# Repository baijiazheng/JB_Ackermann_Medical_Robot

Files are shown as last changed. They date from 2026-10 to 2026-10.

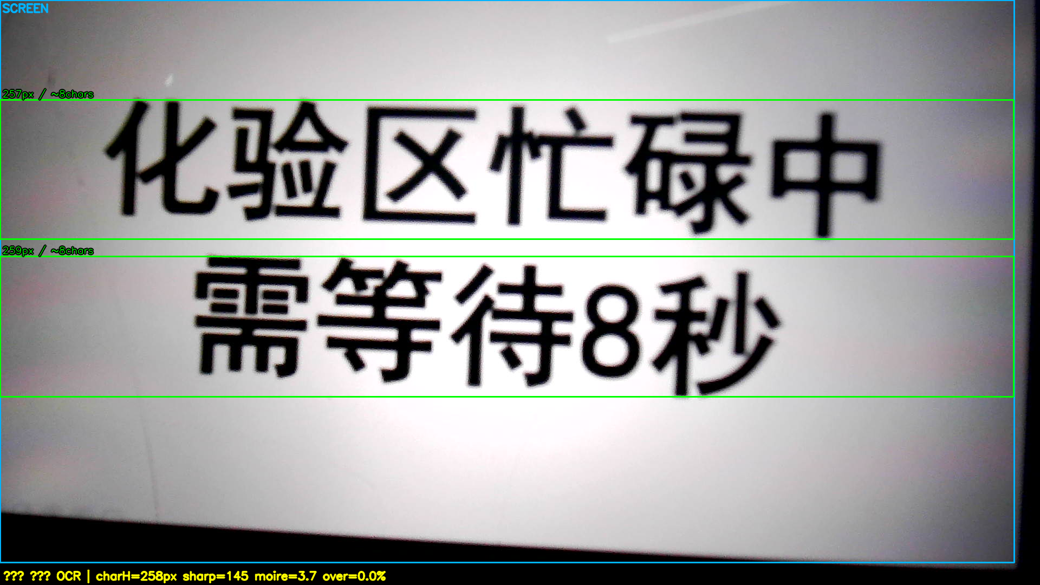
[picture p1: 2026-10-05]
experiments/01-拍屏OCR可行性/shots/annotated/shot_20261005_204455_01.png

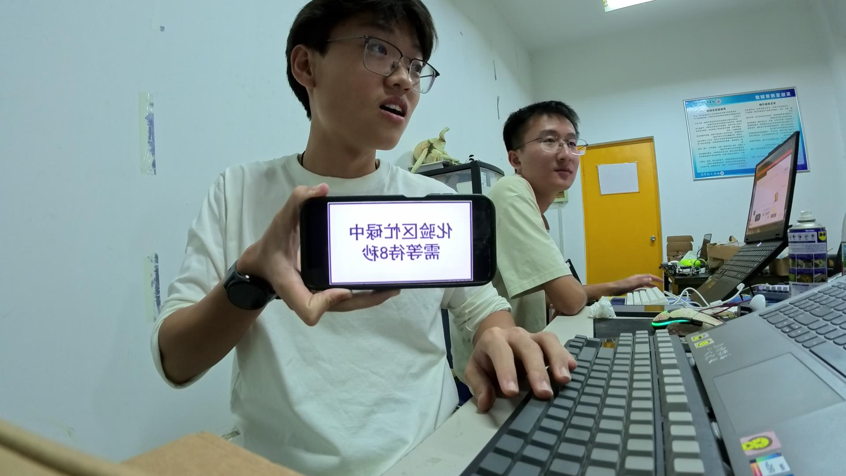
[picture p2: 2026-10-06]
experiments/01-拍屏OCR可行性/shots/shot_20261005_210529_01.png

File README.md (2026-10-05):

# JB_Ackermann_Medical_Robot

> **华北五省（市、自治区）大学生机器人大赛 · 智慧医疗服务机器人（专项赛道）**
> 一台**可无限复用的阿克曼底盘**，本轮承载「智慧医疗服务机器人」任务。

---

## 这是什么

一台能**看懂信息 → 说出来 → 自己开进框**的阿克曼底盘小车。

```
摄像头看到二维码/标签
      ↓
上位机（RDK X3 + ROS2）识别语义，判断"指向哪个体检窗口、什么样本"
      ↓
下发目标转角 δ + 目标速度 v
      ↓
下位机（Mega2560 背板）执行：舵机转向 + I²C 电机 + 语音播报
      ↓
AS5600 实测转角 + 编码器里程 + MPU6050 姿态 + 磁定位 → 闭环
      ↓
精准开进框
```

## 核心设计取向

| 取向 | 说明 |
|---|---|
| **阿克曼转向** | 比赛规则硬性要求（`底盘结构：阿克曼结构`）|
| **底盘永久复用** | 机械 + 背板 + 线束一次做对；以后换主控/换任务只动局部 |
| **三层分离** | 上位机（感知/决策）· 下位机（执行）· 外设接口板（背板，不变）|
| **全程端子** | 不用杜邦线 |
| **算法在上位机** | 下位机只做「指令 → 执行」，不写 PID |

## 目录

```
├── docs/                     方案与决策
│   ├── 01-比赛任务与规则.md
│   ├── 02-系统架构.md
│   ├── 03-阿克曼底盘参数.md     ★ 整车几何基准（唯一有效参数源）
│   └── 04-软件架构.md
├── hardware/
│   ├── mechanical/           机械件
│   │   ├── STL/              导出模型（转向节 / 底板 / 前桥 / 装配）
│   │   └── 图纸/             实测与定位尺寸图
│   └── electronics/          电控（BOM / 接线）
├── firmware/                 下位机（Arduino / 未来 STM32）
│   └── include/HW_CONFIG.h
└── ros2_ws/                  上位机（ROS2）
```

## 关联仓库

| 仓库 | 内容 |
|---|---|
| **[JB_Board](https://github.com/baijiazheng/JB_Board)** | 控制板家族 —— 本车用 **V1.2 阿克曼底盘背板** |
| [JB_AprilTag_Tracker](https://github.com/baijiazheng/JB_AprilTag_Tracker) | 视觉追踪（前代项目，代码可复用）|

## 进度

| 模块 | 状态 |
|---|---|
| 转向节（羊角）| ✅ 建模完成 |
| 前桥横梁 / 底板 | ✅ 建模完成 |
| 车架 | 🚧 待画 |
| 控制板 V1.2 | 🚧 设计输入完成，待画板 |
| 上位机软件 | ⏳ 等硬件 |
| 下位机固件 | ⏳ 等硬件 |

## 关键时间点

- 校赛答辩：**2026-09-23** ✅ 已通过
- 采购下单 T-22：**2026-10-12**

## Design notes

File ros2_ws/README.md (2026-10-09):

# ros2_ws · JB 阿克曼底盘上位机工作区

> **在本机写代码 → 验证语法 → `scp` 到 RDK X3 编译运行**
> （X3 上直接用 SSH 编辑不方便，所以本地开发 + 远程部署）

## 环境

| 项 | 值 |
|---|---|
| **目标板** | RDK X3（`ssh rdk`，IP `192.168.172.236`）|
| **系统** | Ubuntu 22.04.5 LTS / 内核 4.14.87 aarch64 |
| **ROS** | Humble（`/opt/ros/humble` + `/opt/tros/humble` TogetheROS）|
| **工作区** | X3 上 `~/ros2_ws`（本机这个目录是源码镜像）|

## 部署流程

```bash
# ① 本机写代码
cd ~/JB_Ackermann_Medical_Robot/ros2_ws/src/<包名>

# ② 本机语法检查（不需要 ROS 环境）
python3 -c "import ast;ast.parse(open('xxx.py',encoding='utf-8').read())"

# ③ 传到 X3
scp -r <包名> rdk:~/ros2_ws/src/

# ④ X3 上编译运行
ssh rdk
source ~/ros2_ws/setup_env.sh
cd ~/ros2_ws && colcon build --packages-select <包名>
ros2 run <包名> <可执行名>
```

## 已有的包

### `jb_camera_test` —— 摄像头测试

| 可执行 | 作用 |
|---|---|
| `camera_test` | 打开 USB 摄像头，发 `/camera/image_raw`，打印实测分辨率/帧率 |
| `camera_sub` | 订阅图像，统计帧率 + **端到端延迟**，可按需存图 |

**跑法：**
```bash
ros2 launch jb_camera_test camera_test.launch.py
# 或单独跑
ros2 run jb_camera_test camera_test --ros-args -p device:=/dev/video8
ros2 run jb_camera_test camera_sub  --ros-args -p save_every_n:=30
```

**实测结果（2026-10-09）：**
```
摄像头 /dev/video8  →  1280x720 @ 30fps  MJPG
发布/订阅帧率: 20.1 fps（USB 2.0 带宽上限）
★ 端到端延迟: 平均 19ms，最大 55ms   → 1m/s 下车只走 1.9cm，完全够用
```

## ⚠️ 踩过的坑

| # | 坑 | 修法 |
|---|---|---|
| **1** | **`ros2 run` 报 `No executable found`，但 colcon 编译"成功"** | **ament_python 包必须有 `setup.cfg`**（指定 `script_dir=$base/lib/<包名>`）否则脚本装不到 `ros2 run` 能找到的地方 |
| **2** | 摄像头只有 640x480，达不到 720p | **必须显式设置 MJPG**：`cap.set(cv2.CAP_PROP_FOURCC, fourcc('MJPG'))`。USB 2.0 带宽不够跑 YUYV 720p |
| **3** | 请求 1920x1080 却拿到别的分辨率 | 摄像头不一定给要的值 → **必须读回实际值**（`cap.get(CAP_PROP_FRAME_WIDTH)`）|

## 硬件设备

| 设备 | 节点 | 说明 |
|---|---|---|
| **摄像头** | `/dev/video8` | USB 2.0 Camera (Microdia)，video0~7 是地平线 ISP 虚拟节点 |
| **雷达** | `/dev/ttyUSB0` | CP2102 USB-UART 桥（待接）|

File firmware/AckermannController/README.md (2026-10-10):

# AckermannController · 阿克曼底盘下位机固件

> **目标板**：RobotDyn Mega 2560 PRO MINI
> **基于**：`JB_AprilTag_Tracker/firmware/Mega2560` 改造（复用 `MotorDriverI2C` + `UartProtocol`）

## 整体架构

```
RDK X3（上位机）                   Mega2560（下位机）
┌──────────────┐   Serial1    ┌──────────────────────┐
│ 视觉 / 雷达   │ ──────────→  │ UartProtocol 解析指令 │
│ 决策         │  v, ω        │        ↓             │
└──────────────┘              │ AckermannDrive       │
                              │   ├→ ServoSteering → 舵机 D5
                              │   └→ MotorDriverI2C → 电机模块 I²C 0x34
                              └──────────────────────┘
```

## 文件

| 文件 | 作用 |
|---|---|
| `include/AckermannConfig.h` | ★ **所有参数集中在这**（舵机标定、几何、限幅）|
| `include/ServoSteering.h` + `src/` | 舵机控制（标定表 + 线性插值）|
| `include/AckermannDrive.h` + `src/` | ★ **阿克曼运动学**（ω → δ 反算）|
| `include/MotorDriverI2C.h` + `src/` | 电机驱动（**原样复用**，未改）|
| `include/UartProtocol.h` + `src/` | 串口协议（**原样复用**，未改）|
| `src/main.cpp` | 主循环 + 超时保护 |

## ★ 核心知识点

### 1. 阿克曼 vs 差速（运动学）

```
差速车：输入 (v, ω)  →  左轮 = v - ωW/2,  右轮 = v + ωW/2
        → 能原地转圈

阿克曼：输入 (v, δ)  →  后轮 = v,  舵机 = δ
        → 【不能原地转】，最小转弯半径 R = L / tan(δ)
```

**为了兼容 ROS 的 `cmd_vel`（上位机发的是 `v, ω`），下位机内部做反算：**

```
δ = atan( ω · L / v )

推导：ω = v/R，而 R = L/tan(δ)
     → ω = v·tan(δ)/L
     → tan(δ) = ω·L/v
```

**⚠️ `v→0` 时会除零**。物理意义：车不动不可能有角速度。
代码里的处理：`v < 2cm/s` 时视为"原地打方向"（舵机转到位，车不走）。

**★ 最小转弯半径**（决定能不能进框）：
```
R_min = L / tan(δ_max) = 200 / tan(35°) = 286 mm
```

### 2. 舵机标定表（不是线性公式）

```cpp
角度  -20   -10     0    +10   +20   +35   度
脉宽  1709  1604  1500   1391  1275  1098  µs
```

**为什么不用线性公式**：舵机内部 + 连杆几何 + 安装误差都是非线性的，
实测标定比公式准（代价是多标几个点）。

**⚠️ 已知问题**：表格是 `[-20° ~ +35°]`，**左右不对称**。
右转实际极限只有 20°，左转 35°。**待白佳正确认是机械限制还是标定未完成。**

### 3. 指令超时保护（安全必需）

```cpp
if (millis() - g_lastCmdMs > CMD_TIMEOUT_MS) {   // 500ms
    g_drive.stop();     // 上位机断了 → 必须停车
}
```

**★ 不做的后果**：上位机崩溃/线松 → 车继续执行最后指令 → **一直往前冲**。
这是机器人安全的基本要求，不能省。

## 编译烧录

```bash
# 用 Arduino IDE 或 PlatformIO
# 把 include/ 和 src/ 里的文件加进工程
# 板子选 "Arduino Mega or Mega 2560"，处理器 "ATmega2560"
```

## ⚠️ 装好后必须标定的三件事

| # | 标定项 | 怎么做 |
|---|---|---|
| **1** | **电机方向** | 发正速度，看哪个轮子反转 → 在 `applyMotor()` 里改符号 |
| **2** | **舵机中位** | 发 `steer=0`，看前轮是不是正的 → 不是就调 `SERVO_US_CENTER` |
| **3** | **转向极限** | 左右各打到底，确认没顶死（顶死会烧舵机）|

## 待确认

- [ ] **转向左右极限对称吗？**（标定表是 -20~+35，不对称）
- [ ] **轮径**（`WHEEL_DIAMETER_MM = 65`，实测后改）
- [ ] **电机方向**（装好后实测）

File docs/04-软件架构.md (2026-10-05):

# 04 · 软件架构

## 上位机（ROS2）

```
ros2_ws/src/
├── jb_vision/          视觉：二维码/标签识别 → 语义
│   ├── 节点：camera_node（取流）
│   ├── 节点：detector_node（检测）
│   └── 节点：interpreter_node（语义 → 目标窗口/样本）
├── jb_decision/        决策：进框路径 + 语音内容生成
│   └── 节点：mission_node（状态机）
├── jb_control/         控制：轨迹 → (δ, v)
│   └── 节点：ackermann_node（阿克曼运动学）
├── jb_serial/          通信：与下位机的 UART 协议
│   └── 节点：serial_bridge
└── jb_bringup/         总启动
```

### 阿克曼运动学（核心）

```python
# 输入：线速度 v、角速度 ω
# 输出：前轮转角 δ、后轮线速度 v
R = v / ω                          # 转弯半径
delta = atan(L / R)                # L = 轴距 = 200mm
# 约束：
#   |delta| <= delta_max (35°)
#   若 |delta| 超限 → 限速，不做原地转
```

## 下位机（Arduino / 未来 STM32）

```
firmware/
├── include/HW_CONFIG.h      引脚定义（唯一来源）
└── src/
    ├── main.cpp             主循环（定时器调度）
    ├── cmd_parser.cpp       UART 协议解析
    ├── servo_ctrl.cpp       舵机 PWM（脉宽表标定）
    ├── motor_i2c.cpp        hiwonder 模块 I²C 驱动
    ├── feedback.cpp         AS5600 / MPU6050 / 电压
    └── audio.cpp            JQ8900 播放控制
```

### 舵机脉宽标定（已定）

| 左轮转角 | −20° | −10° | **0°** | +10° | +20° | **+35°** |
|---|---|---|---|---|---|---|
| **脉宽 µs** | 1709 | 1604 | **1500** | 1391 | 1275 | **1098** |

## ★ 可复用的前代资产（`JB_AprilTag_Tracker` 实测可用）

| 文件 | 内容 | 复用方式 |
|---|---|---|
| `firmware/.../MotorDriverI2C.h/.cpp` | **I²C 电机驱动完整实现** | **直接抄** —— 地址 `0x34`、寄存器表、方向极性 |
| `firmware/.../UartProtocol.h/.cpp` | **上位机通信协议**（cmd_vel 风格）| **直接抄** |
| `firmware/.../MPU6050.h/.cpp` | IMU 驱动 | 直接抄 |
| `firmware/.../DifferentialDrive.h/.cpp` | 差速底盘抽象 | **改成 AckermannDrive** |
| `firmware/.../Scan IIC.cpp` | I²C 扫描器 | **调试救命用** |
| `upper_computer/src/ysbl_control/control_node.py` | 上位机控制节点 | 参考 |

### I²C 地址（已确认，三者不冲突）

| 器件 | 地址 |
|---|---|
| **hiwonder 四路编码电机模块** | **`0x34`** |
| **AS5600**（转向角）| **`0x36`** |
| **MPU6050** | **`0x68`** |

### ★ 复用关键：接口一模一样

**前代（差速）：**
```cpp
class DifferentialDrive {
    void setVelocity(float linearX, float angularZ);   // m/s, rad/s
};
```

**本代（阿克曼）—— 接口刻意保持一致：**
```cpp
class AckermannDrive {
public:
    AckermannDrive(MotorDriverI2C& motor, Servo& servo);
    void begin();
    void setVelocity(float linearX, float angularZ);   // ← 同样的签名
    void stop();
private:
    MotorDriverI2C& motor;
    Servo& servo;
    float wheelbase = 200.0f;       // 轴距 L (mm)
    void computeSteering(float linearX, float angularZ,
                         float& deltaDeg, float& speed);
};
```

**→ 上位机的 UART 协议、指令格式、ROS2 节点全都不用改，只换下位机执行层。**

### 阿克曼执行层（与差速的唯一区别）

```cpp
// 输入：linearX (m/s), linearZ (rad/s)
if (fabs(angularZ) < 1e-3) {
    deltaDeg = 0;                       // 直行，前轮回正
} else {
    float R = linearX / angularZ;       // 转弯半径 (mm)
    deltaDeg = atan(L / R) * 180/PI;    // 阿克曼：tan(δ) = L / R
    if (fabs(deltaDeg) > DELTA_MAX) {   // DELTA_MAX = 35°
        // 超出舵机行程 → 限速，不原地转
        linearX *= DELTA_MAX / fabs(deltaDeg);
        deltaDeg = (deltaDeg > 0) ? DELTA_MAX : -DELTA_MAX;
    }
}
// 舵机脉宽（线性插值；标定点 0°=1500µs, +35°=1098µs）
int pulse = 1500 - (int)(deltaDeg * 11.7f);
servo.writeMicroseconds(pulse);
motor.setChassisSpeed(speed, speed);
```

**⚠️ 阿克曼的物理限制**：**不能原地转向**（`linearX = 0` 时 `R = 0`，`δ → 90°`）。
**上位机规划时必须保证 `|linearX| > 0`**，否则下位机应拒绝或强制最小速度。

## 待定

- [ ] 通信协议定稿（帧格式、CRC）
- [ ] 视觉方案定型（二维码库 / 标签类型）
- [ ] 进框策略（视觉伺服 or 路径点）
- [ ] 语音内容表（预存哪几段）

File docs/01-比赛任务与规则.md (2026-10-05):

# 01 · 比赛任务与规则

## 赛事

**华北五省（市、自治区）大学生机器人大赛 · 智慧医疗服务机器人（专项赛道）**
校赛答辩：**2026-09-23** ✅ 已通过

## 任务链（从感知到动作）

```
① 看到信息        二维码 / 标签 / 文字牌
        ↓
② 理解信息指向     判断"去哪个窗口、取什么样本"
        ↓
③ 语音播报        把理解结果说出来
        ↓
④ 精准进框        开到指定区域并停稳
```

## 硬性规则（★ 必须遵守）

| 项 | 要求 | 我们的取值 | 状态 |
|---|---|---|---|
| **底盘结构** | **阿克曼结构** | 阿克曼（主销 W=161, s=38）| ✅ |
| **投影尺寸** | **≥ 270 × 210 mm**（无上限）| 285 × 263 | ✅ |
| **车身高度** | **140 ~ 250 mm** | ⚠️ 待确认（底板顶面 z=98，配件须高出 ≥42mm）| 🚧 |
| **CPU** | ≤ 4 核 @ 1.5 GHz | RDK X3：4×A53@1.5G | ✅ 正好卡线 |
| **RAM** | ≤ 4 GB | RDK X3 4GB | ✅ 正好卡线 |
| **算力（BPU/GPU）** | ≤ 5 TOPS INT8 | RDK X3：5 TOPS | ✅ 正好卡线 |
| **系统** | Ubuntu ≥ 18.04 | | ✅ |
| **控制框架** | **ROS1 / ROS2** | ROS2 | ✅ |

> **★ 三条"正好卡线"**：RDK X3 4GB 的 CPU / RAM / 算力**全部贴在上限** ——
> 不能换更高的型号（如 Orin Nano 8GB），否则违规。

## 采购红线

**单件 < 500 元可报（不限件数）；任一件 ≥ 500 元则整件不可报。**

## 参赛机器人命名 / 标识

见赛事通知（`~/Documents/华航创字〔2026〕51号...校内选拔赛的通知`）

## 待补充

- [ ] 正式比赛时间与地点
- [ ] 场地尺寸与"框"的具体规格
- [ ] 计分细则（进框精度要求）
- [ ] 语音播报是否有内容要求

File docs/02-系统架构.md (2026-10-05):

# 02 · 系统架构

## 三层分离

```
┌──────────────────────────────────────────────────────────┐
│ 【上位机】RDK X3 4GB · Ubuntu · ROS2                     │
│   感知：摄像头（200万像素 30fps）→ 二维码/标签识别       │
│   语义：理解信息指向 → (目标窗口, 目标样本)              │
│   决策：进框路径 · 语音内容                              │
│   定位：YDLIDAR T-mini Plus（直插上位机）                │
│   闭环：接收下位机反馈的转角/里程/姿态                    │
└─────────────────┬────────────────────────────────────────┘
                  │ UART（3.3V ↔ 5V 需电平处理）
                  │ 协议：定长帧 + 校验 + 心跳
┌─────────────────▼────────────────────────────────────────┐
│ 【下位机】Mega 2560 PRO MINI（插在 JB_Board V1.2 上）    │
│   接收：目标转角 δ + 目标速度 v                          │
│   执行：舵机 PWM · I²C 电机指令                          │
│   反馈：AS5600 转角 · 编码器里程 · MPU6050 姿态          │
│   播报：JQ8900-16P 语音                                  │
│   保护：看门狗 · 失联停车 · 电池低压                     │
└─────────────────┬────────────────────────────────────────┘
                  │ I²C（3.3V）+ PWM + UART
┌─────────────────▼────────────────────────────────────────┐
│ 【外设层】                                                │
│   hiwonder 四路编码电机模块 · 舵机 TBSN-K15              │
│   AS5600 · MPU6050 · JQ8900-16P + 4Ω3W 喇叭              │
│   电源：3S 11.1V → 电机直供 / 7.4V 舵机 / 5V / 3.3V      │
└──────────────────────────────────────────────────────────┘
```

## 为什么这么分

| 决策 | 理由 |
|---|---|
| **算法全在上位机** | 比赛规则要求 ROS1/ROS2；下位机算不动视觉 |
| **下位机只做「指令→执行」** | 换主控（Arduino→STM32）时上位机代码一行不改 |
| **外设接口板独立（JB_Board V1.2）** | 背板和线束永久复用，换主控只换排母那块 |
| **电机/编码器走 I²C** | hiwonder 模块自带闭环，**下位机不写 PID**，省 10 个引脚 |

## 数据流

### 上行（下位机 → 上位机）
```
转向角实际值（AS5600）· 左右轮里程（编码器）· 姿态（MPU6050）· 电池电压 · 状态字
```

### 下行（上位机 → 下位机）
```
目标转角 δ · 目标速度 v · 播报指令（哪一段音频）· 使能/急停
```

## 通信协议（待定稿）

| 项 | 建议 |
|---|---|
| 波特率 | **115200**（舵机+电机+I²C 之外余量足）|
| 帧格式 | 帧头(2B) + 长度(1B) + 命令(1B) + 数据(nB) + CRC16(2B) |
| 周期 | 上行 50Hz（20ms），下行 20Hz |
| 心跳 | 上位机 100ms 未发 → 下位机自动停车 |

## 关键路径的实时性

| 环节 | 周期 | 说明 |
|---|---|---|
| 舵机 PWM | 50Hz（20ms）| 标准舵机 |
| AS5600 采样 | 100Hz | I²C 读取 |
| 电机指令 | 50Hz | I²C 下发 |
| 上位机视觉 | 30fps（33ms）| 摄像头帧率 |
| **端到端延迟目标** | **< 100ms** | 视觉→转向生效 |

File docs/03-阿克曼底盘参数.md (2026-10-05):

# 03 · 阿克曼底盘参数（★ 唯一有效参数源）

> **方案改过 3 次。** 这份是**唯一基准** —— 建模、采购、写代码**只认这一页**。
> 最后更新：2026-10-05 ｜ 状态：转向节 ✅ 已完成，前桥/底板 ✅ 已建模

---

## 一、⚠️ 已废弃的取值（别用）

| 参数 | ❌ 废弃 | ✅ **当前** | 废弃原因 |
|---|---|---|---|
| 主销中心距 W | 190 | **161** | 参照 ROSMASTER 统一前后轮距 |
| 主销偏移距 s | 32 → 38 | **38** | 轮轴座外移（让主销两端可锁）|
| 前轮距 | 254 → 225 → 237 | **237** | 同上 |
| 臂内偏角 φ | 30.6° → 36.5° → 32.7° | **33.7°** | 三次几何重算 |
| 横拉杆 n | 154.37 → 148.36 → 123.18 | **122.16** | 同上 |
| 球头 P₀ | (169.9,77.2) → … → (170.5,61.6) | **(170.9, 61.1)** | 同上 |
| 舵机 S | (180,30) → (180,0) → (185,5) | **(185, 5)** | 加"不撞轮"约束后重搜 |
| 直拉杆 c | 32.88 → 29.44 → 50.27 | **46.88** | 保证球头扣装得下 |
| 主销 | ~~M5螺丝~~ → ~~φ5光轴+轴环~~ | **上下两个轴承方案** | 白佳正拍板 |

---

## 二、整车定位

| 项 | **值** |
|---|---|
| **轴距 L** | **200**（前轴 x=200，后轴 x=0）|
| **主销中心距 W** | **161** → 主销 **y = ±80.5** |
| **主销偏移距 s** | **38** → 前轮中心面 **y = ±118.5** |
| **前轮距 / 后轮距** | **237 / 225** |
| **车宽** | **263**（前轮最外，≥210 ✓）|
| **车长** | **285**（前悬 43 / 后悬 42）|
| **🚨 车架宽** | **≤ 161 mm**（前轮转 35° 时最内侧扫到 y=82.3）|
| **车架底板 z** | **88 ~ 98** |
| **🚨 车高** | 规则 **140~250** → 底板顶面 z=98，**最高配件须高出底板 ≥42mm** |

**俯视图**：见 `hardware/mechanical/图纸/08-车架主要定位尺寸.png`

---

## 三、转向机构

| 件 / 参数 | 值 |
|---|---|
| 左/右主销 | **(200, ±80.5)** |
| **转向节臂 m** | **35** |
| **臂内偏角 φ** | **33.7°**（相对车纵轴，向后·向内）|
| **球头中心 P₀ / Q₀** | **(170.9, ±61.1)** |
| **横拉杆 n**（球心距） | **122.16** |
| **舵机轴 S** | **(185, 5)** |
| 摆臂 a / 中位 ψ | **35 / 50°** |
| **直拉杆 c**（球心距） | **46.88** |
| 舵机行程 / 最差传力角 | 57.0° / 60.6° |
| **阿克曼误差** | **0.653°**（优秀）|

### 阿克曼原理（正确公式）

```
cot(δo) − cot(δi) = K / L     其中 K = 轮距（不是 W！）

★ 经典公式 cot(δo)−cot(δi) = W/L 只在【主销偏移距 s = 0】时成立。
  本车主销在轮内侧 s=38mm，必须用 K = (W + 2s) 修正。
  若误用经典公式，35° 时误差可达 2.47°。
```

### 转向节 z 分层

| 部件 | z 范围 |
|---|---|
| 车架底板 | 88 ~ 98 |
| 前桥横梁 / 上主销座 | 76 ~ 88 |
| 下主销座 | 18 ~ 30 |
| **转向节套筒** | **28 ~ 78**，内孔 **φ17**（装 2× 606ZZ）|
| **轮轴座** | y **87.5 ~ 103.5**，z 21 ~ 44，内孔 **φ17** |
| 65mm 轮子 | z 0 ~ 65 |

---

## 四、舵机脉宽标定

| 左轮 δL | −20° | −10° | **0°** | +10° | +20° | **+35°** |
|---|---|---|---|---|---|---|
| **脉宽 µs** | 1709 | 1604 | **1500** | 1391 | 1275 | **1098** |

---

## 五、整车零件（终版）

| # | 件 | 规格 | 数量 | 状态 |
|---|---|---|---|---|
| 1 | **转向节轴承** | **606ZZ（6×17×6）** | 4 | 上下各一 |
| 2 | 轮轴轴承 | 606ZZ | 4 | |
| 3 | M6 半牙内六角螺丝 | 光杆段 ≥20mm | 2~4 | 轮轴 |
| 4 | 球头拉杆总成 | M3；**拉杆 35mm ×2、110mm ×1** | 3 | ⚠️ 需换货 |
| 5 | M3 热熔铜螺母 | M3 | 20 | |
| 6 | M3 螺丝螺母套装 | M3×6/8/10/12/16/20 | 1 包 | |
| 7 | **AS5600 模块 + 径向磁铁** | 带**径向充磁**磁铁 | 1 | |
| 8 | DC-DC 降压模块 | 12V→7.4V **≥5A** | 1 | |
| 9 | 自恢复保险丝 | 5A | 2 | |
| 10 | **RDK X3 4GB** | 二手 | 1 | |
| 11 | **YDLIDAR T-mini Plus** | | 1 | |
| 12 | 85mm 六角联轴器 | 老车复用 | 2 | |
| 13 | 65mm 轮子 | 老车复用 | 4 | |
| 14 | **JQ8900-16P + 4Ω3W 喇叭** | 语音播报 | 1 | |

**已取消**：~~MR105ZZ~~、~~顶丝轴环~~、~~M5 螺母/开口销~~、~~φ5 光轴~~、~~m6 D型轴~~

---

## 六、材料与工艺

| 件 | 材料 | 要求 |
|---|---|---|
| 转向节 / 前桥 | **PETG**（或玻纤，⚠️ 见下）| 填充 ≥50%，壁 ≥1.6mm，层高 0.2 |
| 底板 / 车架 | **玻纤板** | CNC/激光切；**切割粉尘有毒，戴 N95** |
| 舵机座 | **CNC 钣金** | 折弯件 |
| 车架 | 待定 | |

> ⚠️ **玻纤做羊角有风险**：FR4 是层压板，**层间强度远低于平面内**，受弯矩+冲击容易劈裂。
> 若坚持用，须**多层叠压 + 纤维方向交错 + 厚度 ≥5mm**。

**打印朝向**：转向节**竖着打**（套筒轴 = 打印 Z），让轮轴座的弯曲应力落在平面内。

---

## 七、待确认

- [ ] **转向节实际尺寸核对**（STL 已导出，见 `hardware/mechanical/STL/`）
- [ ] **前轴在车长方向的 Z 位置**（决定底板前端要不要收窄到 161）
- [ ] KBA 带螺杆轴承：螺杆在内圈还是外圈（若仍用）
- [ ] 球头拉杆换货（50→35mm、125→110mm）
- [ ] 车高能不能到 140（最高配件须高出底板 ≥42mm）

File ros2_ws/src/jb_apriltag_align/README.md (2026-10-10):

# jb_apriltag_align · 最小视觉闭环

> **摄像头 → AprilTag 检测 → P 控制 → 串口 → 下位机 → 车动 → 回到摄像头**

## 闭环结构

```
                    ┌──────────────────────────────────────┐
                    │                                      │
   ┌────────┐   ┌───▼────┐   ┌────────┐   ┌────────┐   ┌──▼───┐
   │ 摄像头  │──→│ AprilTag│──→│ P 控制器│──→│ 串口    │──→│ 下位机 │
   │/video8 │   │  检测   │   │ (v, ω) │   │ttyS0   │   │Mega  │
   └────────┘   └────────┘   └────────┘   └────────┘   └──┬───┘
        ↑                                                  │
        └──────────────── 车动了，图像变了 ─────────────────┘
```

## ★ 为什么用视觉伺服而不是 SLAM（做最小闭环）

| | **AprilTag 视觉伺服** | **SLAM（gmapping）** |
|---|---|---|
| 输出 | **相对目标的横向/纵向误差** | 全局位姿 + 地图 |
| 适合 | **对准、进框** | 从 A 开到 B |
| 需要 | **只有摄像头（已有）** | **里程计 odom + 雷达 + 建图时间** |
| 现在能跑吗 | ✅ **今天就能** | ❌ **AS5600 没到，odom 做不了** |

**→ 结论：最小闭环 = AprilTag 视觉伺服。SLAM 是后续加分项。**

## 控制律（P 控制器）

```
横向误差 ex_norm = (标签中心x - 图像中心x) / 图像中心x     归一化到 [-1,1]

纵向距离 dist = (标签真实边长 × 焦距) / 标签像素边长         针孔模型单目测距
纵向误差 ez   = dist - target_dist

线速度  v = Kp_dist × ez      限幅 [v_min, v_max]，dist<stop_dist 时 v=0
角速度  ω = -Kp_yaw × ex_norm 限幅 ±w_max（负号：标签偏右→右转→ω为负）
```

**★ 为什么用 P 不用 PID**：视觉伺服的误差本身快速变化，积分项易累积过冲，
微分项对图像噪声敏感。**P 够用，调参简单（只有 2 个参数）。**

**★ 阿克曼特性**：`ω` 只在有速度时有效。`v=0` 而 `ω≠0` 时，下位机做"原地打方向"
（舵机转到位但车不动）—— 对准时这反而好（先打死方向再走）。

## 串口协议

```
发送:  "V,<linearX>,<angularZ>\n"
  linearX  : m/s     前进速度（负=后退）
  angularZ : rad/s   角速度（正=左转）
```

**与下位机 `UartProtocol.cpp` 的解析完全对应。**

## 跑法

```bash
# 一键：摄像头 + 对准节点
ros2 launch jb_apriltag_align align.launch.py

# 直接跑
ros2 run jb_apriltag_align align_node \
  --ros-args -p port:=/dev/ttyS0 -p tag_id:=0 -p target_dist:=0.5 \
             -p kp_dist:=1.2 -p kp_yaw:=2.0
```

## 调参指南

| 现象 | 调什么 |
|---|---|
| **冲过头** | 降 `kp_dist` 或降 `v_max` |
| **走太慢/走不动** | 升 `v_min`（电机死区）|
| **左右摆（震荡）** | 降 `kp_yaw` |
| **对不准 / 反应迟钝** | 升 `kp_yaw` |
| **停得太远/太近** | 调 `stop_dist` / `target_dist` |

## ⚠️ 必须先做的事

### 1. 标定相机内参（否则测距不准）

**代码里的 `fx=fy=700, cx=640, cy=360` 是【估计值】，正式用必须标定。**

```bash
# 用棋盘格标定，得到 camera_matrix 和 dist_coeffs
# 参考 JB_AprilTag_Tracker/upper_computer/src/ysbl_vision/ 里的标定脚本
# 标定后改 align_node.py 里的 fx/fy/cx/cy
```

### 2. 打印 AprilTag（tag36h11，ID=0，边长 50mm）

**⚠️ 打印时不要缩放！** 缩放了实际边长就变了，测距会偏。
打印后**用尺子量一下实际边长**，改 `tag_size` 参数。

### 3. 确认下位机波特率和串口

**RDK X3 的串口**：
- `/dev/ttyS0`（40PIN 上的 UART，要 `sudo` 或加入 `dialout` 组）
- 或 USB-TTL 转接：`/dev/ttyUSB0`

## 已知问题

| # | 问题 | 状态 |
|---|---|---|
| 1 | **OpenCV 4.7+ aruco API 大改** | ✅ 已兼容新旧两套 API |
| 2 | **pupil_apriltags 未装** | ⚠️ 用 cv2.aruco 替代（够用）|
| 3 | **相机内参未标定** | 🚧 用估计值，影响测距精度 |
| 4 | **单目测距只在标签正对时准** | ⚠️ 倾斜时误差大（可用 PnP 改善）|

## 实测记录（2026-10-10）

```
✅ OpenCV 4.11 新 aruco API 初始化成功
✅ 合成 AprilTag 图检测: 找到 ID=0
✅ 节点参数加载正确
✅ 无标签时正确"停车等待"
✅ 退出时自动发停车指令
```

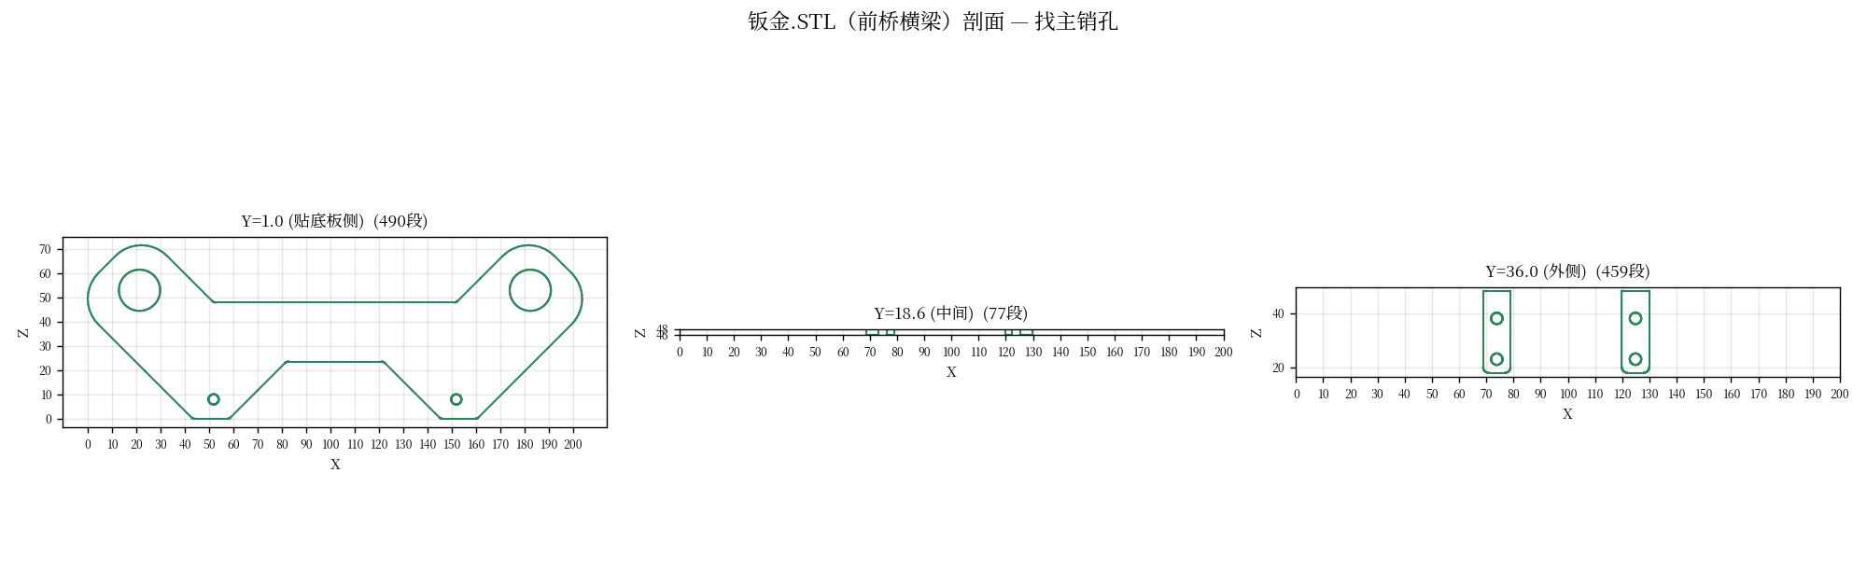
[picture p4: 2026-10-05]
hardware/mechanical/图纸/11-钣金剖面.png

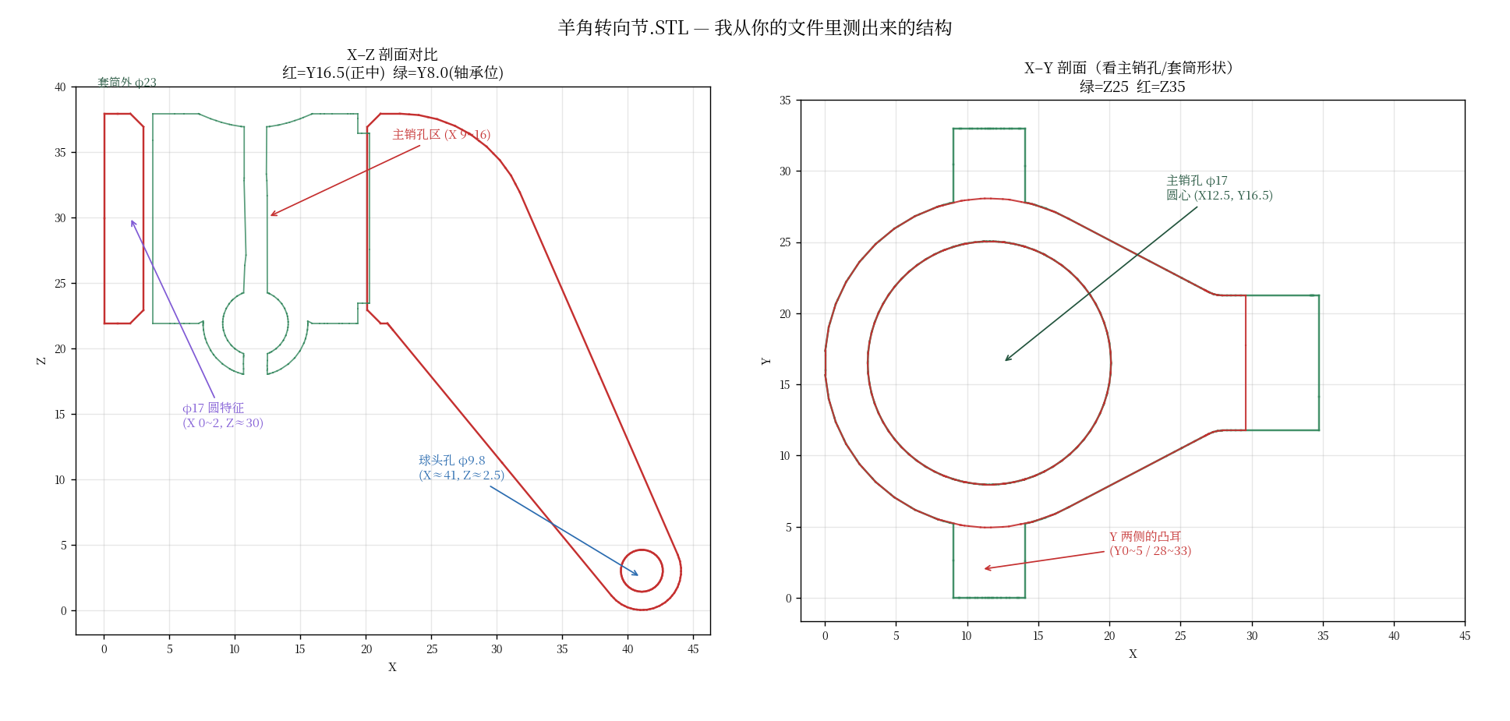
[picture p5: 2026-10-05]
hardware/mechanical/图纸/09-羊角实测结构.png

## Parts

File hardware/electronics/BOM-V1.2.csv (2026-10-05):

No | Designator | Comment | Value | Footprint | Qty | Mfr Part | LCSC | Note
1 | C1,C2 | 电解电容 | 470uF/25V | CAP-TH_BD6.3-P2.5 | 2 | GR1C471M0611 | C2873966 | V1.1验证
2 | C3,C4,C10-C15 | 去耦电容 | 100nF | C0805 | 10 | FCC0805B104K500DT | C5137467 | V1.1验证
3 | C5,C6 | 电容 | 10uF | C0805 | 2 | CGA0805X5R106K250MT | C6119887 | V1.1验证
4 | C7 | 钽电容 | 22uF/10V | CASE-A_3216 | 1 | TAJA226K010RNJ | C11366 | V1.1验证
5 | R1,R2 | 分压 | 10k | R0805 | 2 | FRC0805J103TS | C2930231 | V1.1验证
6 | R3 | 分压 | 2k | R0805 | 1 | FRC0805J202 TS | C2907315 | V1.1验证
7 | R4,R5 | I2C上拉 | 4.7k | R0805 | 2 |  |  | 搜: 4.7k 0805
8 | R6,R7 | 0欧 | 0R | R0805 | 2 | 0805W8F0000T5E | C17477 | V1.1验证
9 | LED1-LED4 | 指示灯 | 红 | LED0805-RD | 4 | XL-2012SURC | C965812 | V1.1验证
10 | F1 | 自恢复保险 | 5A | R0805 | 1 | SMD0805-100-12 | C46640991 | V1.1验证
11 | SW1 | 按键 | 5.8轻触 | SW-TH_5.8ZSGT | 1 | 5.8 ZSGT | C2681587 | V1.1验证
12 | D1 | TVS | SMBJ5.0A | SMB | 1 | SMBJ5.0A | C5331094 | V1.1验证
13 | J_BAT | 电池输入 | KF128-2P/XT30 | - | 1 |  |  | 搜: KF128 5.08 2P
14 | J_MOTOR | 电机I2C | 4P XH2.54 | CONN-TH_XH2.54-4P | 1 |  |  | 搜: XH2.54 4P
15 | J_SERVO | 舵机 | 3P XH2.54 | CONN-TH_XH2.54-3P | 1 |  |  | 搜: XH2.54 3P
16 | J_AS5600 | AS5600模块 | 4P XH1.25 | CONN-TH_1.25-4P | 1 |  |  | 搜: GH1.25 4P
17 | J_IMU | MPU6050模块 | 4P XH2.54 | CONN-TH_XH2.54-4P | 1 |  |  | 搜: XH2.54 4P
18 | J_UPC | 上位机UART | 4P XH2.54 | CONN-TH_XH2.54-4P | 1 |  |  | 搜: XH2.54 4P
19 | J_SPK | 喇叭 | 2P XH2.54 | CONN-TH_XH2.54-2P | 1 | SH-XH2.54-2PWZ | C42372642 | V1.1验证
20 | J_5V1,J_5V2 | 5V输出 | 2P XH2.54 | CONN-TH_XH2.54-2P | 2 | SH-XH2.54-2PWZ | C42372642 | V1.1验证
21 | J_ESTOP | 急停 | 2P XH2.54 | CONN-TH_XH2.54-2P | 1 | SH-XH2.54-2PWZ | C42372642 | V1.1验证
22 | J_DBG | 调试串口 | 1x4P排针 | HDR-TH_4P-P2.54 | 1 | HC-PM254-5.0H-1x4PZ-02A | C42163122 | V1.1验证
23 | U_MAIN | 主控排母 | 2x 1x24P | HDR-TH_24P-P2.54-F | 2 |  |  | 搜: 2.54 1x24 母座
24 | U_AUDIO | JQ8900座 | 2x 1x8P | HDR-TH_8P-P2.54-F | 2 | PM2.54-1X8PM-H85 | C42431840 | V1.1验证
25 | U1 | 5V Buck 8A | MP2225 | TSOT-23-8 | 1 |  |  | 搜: MP2225
26 | U2 | 7.4V Buck 5A | 模块 | - | 1 |  |  | 外购模块: 可调降压 5A
27 | U3 | 3.3V LDO | AMS1117-3.3 | SOT-223 | 1 |  |  | 搜: AMS1117-3.3
28 | L1 | Buck电感 | 4.7uH | IND-SMD_L7.3-W6.6 | 1 |  |  | 搜: 4.7uH 一体成型
29 | D2 | 肖特基 | SS34 | SOD-123 | 1 |  |  | 搜: SS34
30 | F2-F4 | 汽车保险丝座 | Mini Blade | 插件 | 3 |  |  | 搜: Mini Blade 保险丝座
31 | U4 | I2C电平转换 | PCA9306 | SOT-23-8 | 1 |  |  | 搜: PCA9306DCUR
33 | TP1-TP12 | 测试点 | 1.5mm | 焊盘 | 12 |  |  | 搜: 测试点 1.5mm

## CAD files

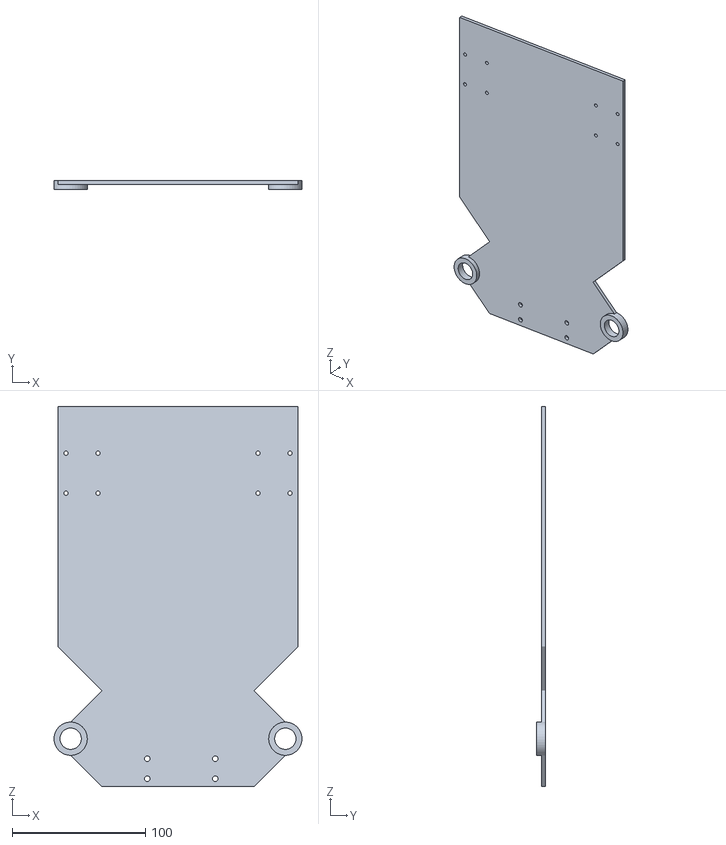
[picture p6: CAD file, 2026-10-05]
hardware/mechanical/STL/装配 - 底板-1.STL
186.0 x 7.00 x 285.0

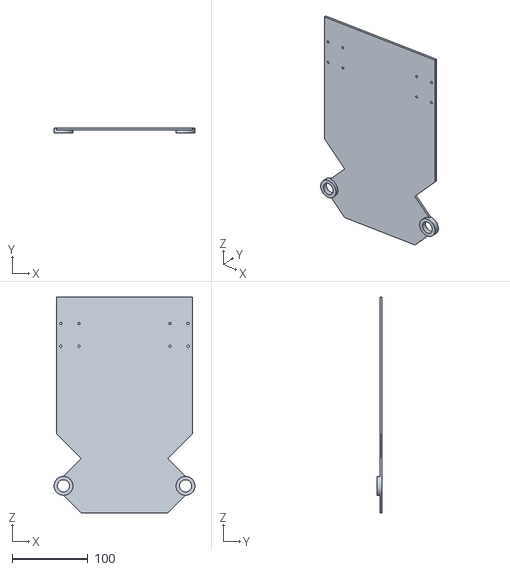
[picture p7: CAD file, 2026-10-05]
hardware/mechanical/STL/底板.STL
186.0 x 7.00 x 285.0

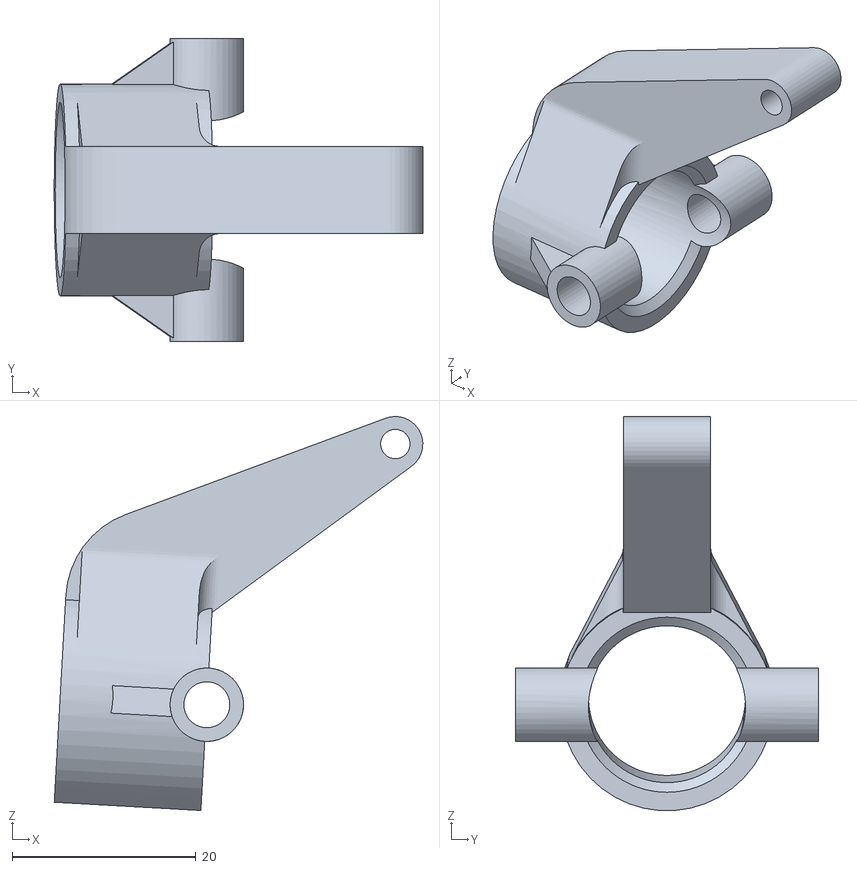
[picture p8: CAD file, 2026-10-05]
hardware/mechanical/STL/装配 - 羊角转向节-1.STL
40.1 x 33.0 x 42.9

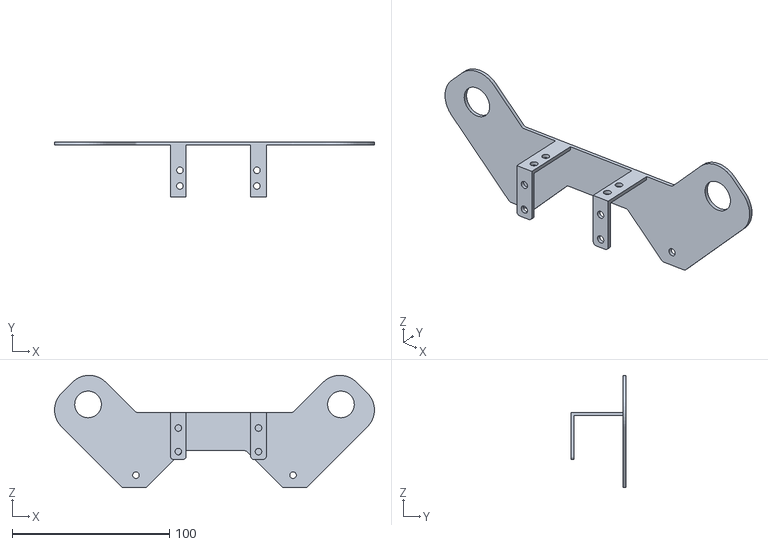
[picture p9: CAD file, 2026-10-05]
hardware/mechanical/STL/装配 - 钣金-1.STL
203.7 x 35.0 x 71.6

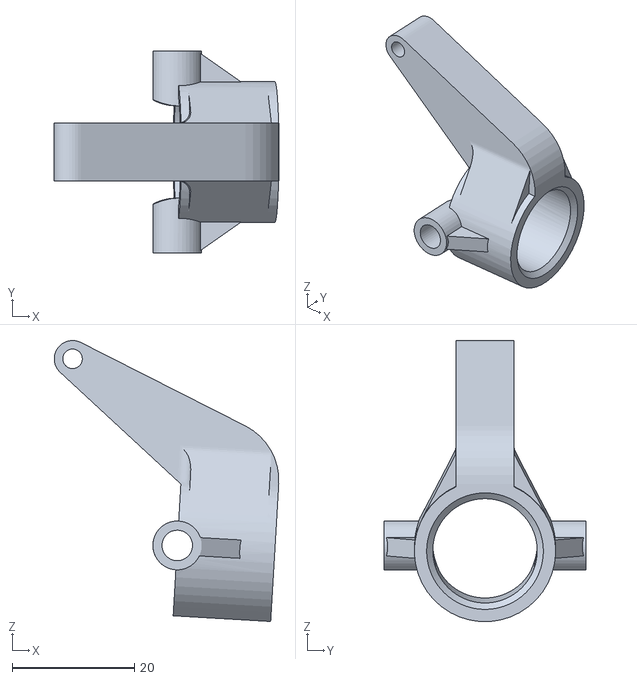
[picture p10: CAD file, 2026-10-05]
hardware/mechanical/STL/装配 - 羊角转向节-2.STL
36.8 x 33.0 x 46.0

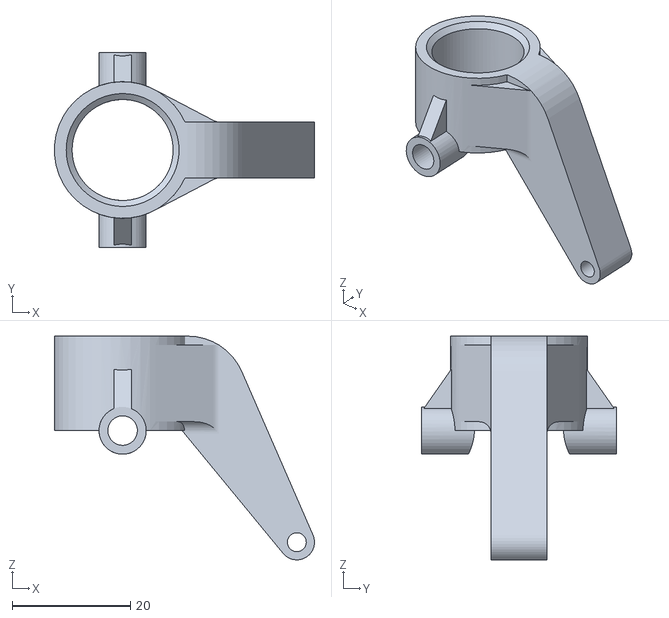
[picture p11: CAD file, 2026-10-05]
hardware/mechanical/STL/羊角转向节.STL
44.0 x 33.0 x 37.9

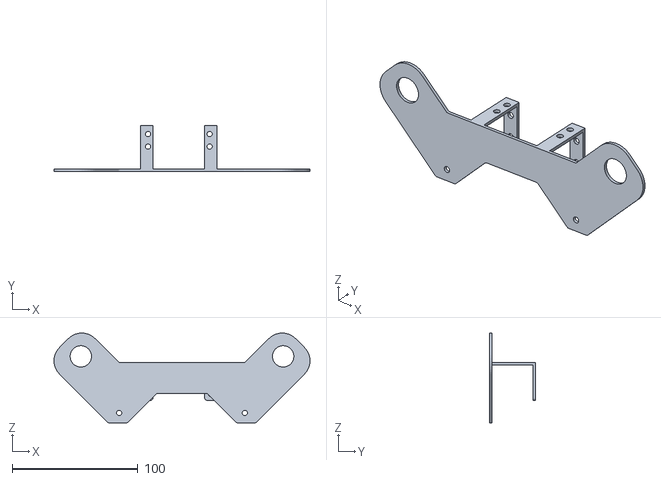
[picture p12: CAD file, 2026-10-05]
hardware/mechanical/STL/钣金.STL
203.7 x 37.0 x 71.6

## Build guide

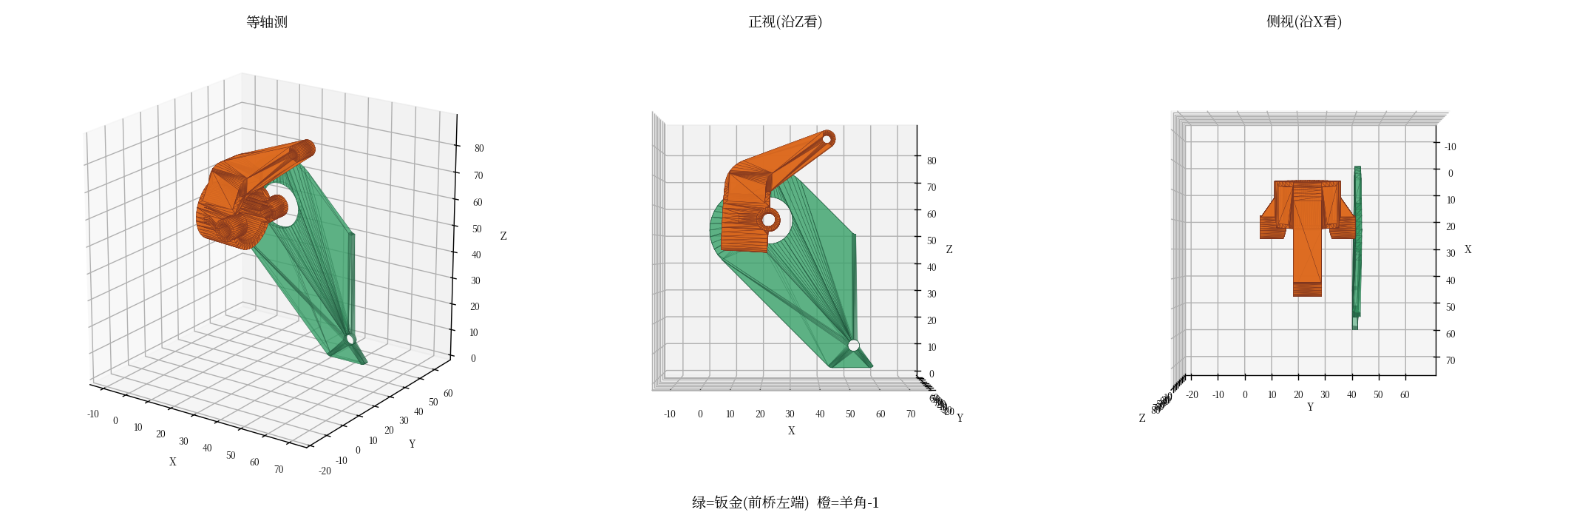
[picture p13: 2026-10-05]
hardware/mechanical/图纸/13-装配局部.png

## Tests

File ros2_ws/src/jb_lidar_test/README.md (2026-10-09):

# jb_lidar_test · 雷达测试包

> 硬件：**YDLIDAR T-mini Plus**（`/dev/ttyUSB0`，230400，型号码 151）

## 两个节点

| 可执行 | 作用 |
|---|---|
| `lidar_test` | 订阅 `/scan`，打印点数/角度范围/最近障碍/前方扇区预警 |
| `lidar_safety` | 分左前/正前/右前三个扇区，发布 `/lidar_safety`（CLEAR/SLOW/STOP）|

## 跑法

```bash
# 一键（驱动 + 测试 + 安全）
ros2 launch jb_lidar_test lidar_test.launch.py

# 或单独跑（驱动要先起来）
ros2 run ydlidar_ros2_driver ydlidar_ros2_driver_node --ros-args \
  -p port:=/dev/ttyUSB0 -p lidar_type:=1 -p sample_rate:=4 \
  -p isSingleChannel:=false -p frequency:=10.0
ros2 run jb_lidar_test lidar_test
ros2 run jb_lidar_test lidar_safety
```

## 实测（2026-10-09）

```
扫描参数: 400 个点 | 角度 -180°~+180° | 步进 0.90° | 量程 0.10~64 m | 一圈 0.100s
有效点: 135~144 / 400（室内，很多角度超量程，正常）
安全节点: 正前 0.29m → 正确判定 STOP
```

## ⚠️ 踩过的坑

### 1. **QoS 不匹配（最隐蔽的坑）**

```
[WARN] New publisher discovered on topic '/scan', offering incompatible QoS.
       No messages will be received from it. Last incompatible policy: RELIABILITY
```

**根因**：`ydlidar_ros2_driver` 用 `BEST_EFFORT` 发布，订阅端默认是 `RELIABLE` → **不兼容，一条数据都收不到，而且不报错！**

**修法**：订阅传感器数据一律用 BEST_EFFORT
```python
from rclpy.qos import QoSProfile, ReliabilityPolicy, HistoryPolicy, DurabilityPolicy
qos = QoSProfile(
    reliability=ReliabilityPolicy.BEST_EFFORT,   # ★ 关键
    history=HistoryPolicy.KEEP_LAST,
    depth=1,
    durability=DurabilityPolicy.VOLATILE,
)
self.create_subscription(LaserScan, '/scan', self.on_scan, qos)
```

> **★ 通用规则**：订阅 **雷达 / 相机 / IMU** 等传感器话题时，
> 一律用 `rclpy.qos.qos_profile_sensor_data` 或手写 `BEST_EFFORT`。

### 2. 驱动默认端口是 `/dev/ydlidar`

需要建 udev 规则软链，或者命令行 `-p port:=/dev/ttyUSB0`：
```bash
echo 'KERNEL=="ttyUSB*", ATTRS{idVendor}=="10c4", ATTRS{idProduct}=="ea60", MODE:="0666", SYMLINK+="ydlidar"' \
  | sudo tee /etc/udev/rules.d/ydlidar.rules
sudo udevadm control --reload && sudo udevadm trigger
```

## T-mini Plus 权威参数

```yaml
port:            /dev/ttyUSB0     # 或 /dev/ydlidar（需 udev）
baudrate:        230400
lidar_type:      1                # TYPE_TRIANGLE（三角测距）
device_type:     0                # TYPE_SERIAL
sample_rate:     4
isSingleChannel: false
frequency:       10.0             # Hz
frame_id:        laser_frame
range_min:       0.02
range_max:       12.0
```

**型号码**：`140=Tmini  150=TminiPro  151=TminiPlus ★  152=TminiPlusSH(森合,TOF)`

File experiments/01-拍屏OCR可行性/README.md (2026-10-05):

# 实验 01 · 拍屏 OCR 可行性验证

> **目的**：在画板/买件之前，先确认「**摄像头拍显示屏上的中文 → OCR 能读出来**」这件事成立。
> **为什么先做**：这是整个视觉方案的地基。图拍不好，模型再强也白搭。
> **成本**：10 分钟。**收益**：可能省掉一整轮返工。

---

## 一、为什么必须做这个实验

拍屏幕有三个**物理层面**的坑，和"选什么 OCR 引擎"无关：

| # | 现象 | 后果 |
|---|---|---|
| **1** | **摩尔纹** —— 摄像头像素网格与屏幕像素网格干涉 | 彩色波纹，**OCR 一个字都读不出** |
| **2** | **刷新条纹** —— 快门与屏幕刷新不同步 | 半亮半暗横条 |
| **3** | **反光 / 过曝** —— 屏幕自发光 | 一片白，字全丢 |

**还有一个数字门槛**：OCR 要求**每个汉字至少 20~32 像素高**，低于 20px 识别率断崖下跌。

---

## 二、硬件事实（2026-10-05 实测）

| 设备 | 最高分辨率 | 说明 |
|---|---|---|
| `/dev/video0` | 1280×720 | ❌ 做 OCR 不够 |
| **`/dev/video2`** | **1920×1080** | ✅ **200万像素，用这个** |

> ⚠️ **不指定设备的话默认给 640×480，别用。**

---

## 三、实验步骤

### 步骤 1 · 探测设备与分辨率

```bash
python3 probe.py
```
**看输出**：记下能给出 1920×1080 的设备号（当前是 `/dev/video2`）。

### 步骤 2 · 拍照片

```bash
# 在预估的比赛距离上，用手机/显示器显示中文，对着拍
python3 capture.py --dev 2 --size 1920x1080
```

**窗口里的按键：**

| 键 | 作用 |
|---|---|
| **空格** | 拍照，存到 `shots/` |
| **+ / -** | 增减曝光（找不过曝的档位） |
| **f** | 切换自动/手动曝光 |
| **s** | 循环切换分辨率 |
| **q** | 退出 |

**★ 拍照要点：**
1. **让屏幕在画面里占够大**（至少 1/3 宽）—— 这是每字像素数的来源
2. **多拍几张不同距离**（比如 30cm / 50cm / 80cm）
3. **多拍几张不同曝光**（看会不会过曝）
4. **顺便拍一张"轻微失焦"的** —— 有时候失焦反而能消摩尔纹

### 步骤 3 · 分析

```bash
python3 analyze.py shots/
# 或分析单张
python3 analyze.py shots/shot_01.png
```

**输出**：每张图的
- 清晰度、摩尔纹强度、曝光评价
- **检测到的文字行数 + 每行字高（像素）**
- **★ 综合判定：能 OCR / 勉强 / 不能**
- 标注图存到 `shots/annotated/`

---

## 四、判定标准

| 指标 | ✅ 能 OCR | ⚠️ 勉强 | ❌ 不能 |
|---|---|---|---|
| **每字像素高** ★关键 | **≥ 25 px** | 20~25 px | **< 20 px** |
| **摩尔纹（峰值突出度）** ★关键 | **< 8** | 8~20 | **> 20** |
| **拉普拉斯方差**（清晰度）| ≥ 150 | 80~150 | < 80 |
| **过曝像素占比** | < 3% | 3~10% | **> 10%** |

**★「字高」和「摩尔纹」是关键项，任一硬失败 → 直接判「不能 OCR」。**

### 摩尔纹指标的真实校准数据（2026-10-05 实测）

| 样本 | **峰值突出度** | 判定 |
|---|---|---|
| 实拍图（肉眼无摩尔纹）| **3.78** | ✅ |
| 合成弱摩尔纹 | 57.9 | ❌ |
| 合成中摩尔纹 | 49.7 | ❌ |
| 合成强摩尔纹 | 50.2 | ❌ |
| 合成极强摩尔纹 | 69.9 | ❌ |

> ⚠️ **踩过的坑**：最初用 `FFT 99.95分位 / 中位数` 做指标，结果是**完全反的**——
> 无摩尔纹图得 45.1，加了摩尔纹反而降到 28~30。
> 正确做法是看**峰值相对局部背景的突出度**（孤立窄峰 = 周期性干涉）。

**四项里有两项以上 ❌ → 视觉方案要重新选**（换摄像头 / 加滤镜 / 改角度 / 改算法）。

---

## 五、如果拍不好，往哪调

| 问题 | 对策（按性价比排序）|
|---|---|
| **摩尔纹严重** | ① 镜头**轻微失焦** ② 换拍摄角度 ③ 加低通滤镜 ④ 换**全局快门**摄像头 |
| **刷新条纹** | 曝光时间**设为 ≥1/50s**，或屏幕刷新周期的整数倍 |
| **过曝** | 关自动曝光 → 手动固定；或限制 AE 上限 |
| **字太小（像素不够）** | ① 摄像头**靠近** ② 换**长焦镜头** ③ 换**更高像素**摄像头 |
| **字糊** | ① 对焦（很多 USB 摄像头能手动调焦）② 增曝光 ③ 稳住不要手抖 |

---

## 六、实验记录（白佳正填写）

| 日期 | 距离 | 分辨率 | 字高px | 清晰度 | 摩尔纹 | 判定 | 备注 |
|---|---|---|---|---|---|---|---|
| | | | | | | | |

---

## 七、这个实验的产出会用到哪

| 产出 | 影响 |
|---|---|
| **能拍清的最小距离 / 最大距离** | → 决定**摄像头安装位置** |
| **能拍清所需的分辨率** | → 决定**摄像头选型**（200万够不够） |
| **摩尔纹严重程度** | → 决定**要不要加滤镜/换全局快门** |
| **每字像素数** | → 决定 **OCR 模型选型**（小模型够不够） |

---

## 八、工具当前能力与已知局限（2026-10-05 诚实交代）

### ✅ 已经可靠的

| 能力 | 状态 |
|---|---|
| **自动找屏幕**（能区分屏幕和白衣服/白墙）| ✅ 实测 4 张都对 |
| **摩尔纹检测** | ✅ 用合成条纹校准过（无 3.8 / 有 50+）|
| **清晰度**（在屏幕区域内算）| ✅ |
| **字高**（行距正常时）| ✅ 实测 26/32/100px 都对 |
| **综合判定「能不能 OCR」** | ✅ 4 张全部判对 |

### ⚠️ 已知局限

| 局限 | 表现 | 影响 | 兜底 |
|---|---|---|---|
| **行距很小会把两行合成一行** | 某张图（屏幕373x242）报「1行」，实际 2 行；字高报 116px（实际约 55px）| **字高偏大 → 偏保守**，不会误判成「不能 OCR」 | 用 `--roi` 只框一行 |
| 字数统计 | 同上图报 23 字（实际 11 字）| 只影响读数，不影响判定 | 同上 |

> **为什么「偏保守」可接受**：它只会把「能」说成「勉强」，不会把「不能」说成「能」。
> 后者才会害你到比赛现场才发现。

### 用法建议

```bash
# 整幅自动分析
python3 analyze.py shots/

# 行距小、或想精确量某一行 -> 手动框选单行
python3 analyze.py shots/xxx.png --roi 950,420,400,70
```

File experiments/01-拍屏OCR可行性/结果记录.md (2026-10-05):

# 拍屏实验 · 结果记录

> 每测一组就填一行。

## ★ 距离-字高对应表（2026-10-05 测 7 组）

**你报的距离：5 / 15 / 20 / 30 / 40 / 50 cm**（按顺序对应下面文件）

| # | 文件 | 屏幕尺寸 | **占画面宽** | **字高** | 清晰度 | 摩尔纹 | 判定 |
|---|---|---|---|---|---|---|---|
| 1 | `..._204455_01` | 1872×1038 | **98%** | **258px** | 145 | 3.70 | ✅ |
| 2 | `..._204533_02` | 1082×629 | **56%** | **145px** | 486 | 3.73 | ✅ |
| 3 | `..._204601_03` | 653×369 | **34%** | **80px** | 1561 | 3.95 | ✅ |
| 4 | `..._204614_04` | ❌ **无** | — | — | 198 | 3.58 | ❌ **曝光不足** |
| 5 | `..._204629_05` | 518×309 | **27%** | **74px** | 1806 | 3.74 | ✅ |
| 6 | `..._204641_06` | 378×210 | **20%** | **43px** | 2111 | 3.67 | ✅ |
| 7 | `..._204653_07` | 292×165 | **15%** | **35px** | 2059 | 3.63 | ✅ |

## ★★★ 结论

1. **15% ~ 98% 占画面宽的范围内，全部可 OCR** —— 字高 35~258px，**最远的 50cm 仍有 35px（门槛 25px）**
2. **字高大致与"占画面宽"成正比**（约占画面宽的 12%）
   - 占 15% → 字高 35px
   - 占 34% → 字高 80px
   - 占 98% → 字高 258px
3. **摩尔纹全部 3.6~4.0** —— 手机屏幕**没有摩尔纹问题**，不需要滤镜
4. **清晰度不是瓶颈** —— 除第1张（145）外都在 486~2111

## ⚠️ 第4张失败的原因（重要数据）

```
全图均值仅 16.3，亮像素 3.4%
→ 手动曝光调得过低，画面暗到屏幕都找不到
```

**这是【曝光下限】的实测边界。** 说明：
- 车在暗环境或曝光设置不当时，**会拍出完全不可用的图**
- **下位机/上位机需要"曝光是否够"的实时判据**（比如亮像素占比 < 2% 就报警）

## ⏳ 待补

- [ ] **20cm 斜拍**（测透视影响）
- [ ] **手抖组**（已知第3张是手抖拍的，但工具没识别出来 → 要加运动模糊判据）

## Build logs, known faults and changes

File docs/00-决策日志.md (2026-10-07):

# 00 · 决策日志

> ## ⚠️ 使用说明（先读这段）
>
> **看这份文件，只看【第一章：当前有效】。**
> **第二章是"已废弃 / 被否的方案"，仅作备查 —— 不要照着做。**
>
> 目的：三个月后回来看板子，能知道"为什么当初这么画"，
> 同时**避免看到旧方案而做错**。

---

# 第一章 · ✅ 当前有效（施工只看这一章）

## 1.1 ★ 关键参数速查表

### 整车几何（权威源：`docs/03-阿克曼底盘参数.md`）

| 参数 | **值** |
|---|---|
| 轴距 L | **200** |
| 主销中心距 W | **161**（主销 y = ±80.5）|
| 主销偏移距 s | **38**（前轮中心面 y = ±118.5）|
| 前轮距 / 后轮距 | **237 / 225** |
| 车宽 / 车长 | **263 / 285** |
| **车架宽上限** | **≤ 161**（前轮转 35° 时最内侧扫到 y=82.3）|
| 车架底板 z | **88 ~ 98** |
| **车高** | 规则 **140~250** → 底板顶面 z=98，最高配件须高出底板 **≥42mm** |
| 转向节臂 m / 内偏角 φ | **35 / 33.7°** |
| 横拉杆 n（球心距）| **122.16** |
| 球头 P₀/Q₀ | **(170.9, ±61.1)** |
| 舵机 S / 摆臂 a / 中位 ψ | **(185, 5) / 35 / 50°** |
| 直拉杆 c（球心距）| **46.88** |
| 阿克曼误差 | **0.653°** |

### 舵机脉宽

| 左轮 δL | −20° | −10° | **0°** | +10° | +20° | **+35°** |
|---|---|---|---|---|---|---|
| 脉宽 µs | 1709 | 1604 | **1500** | 1391 | 1275 | **1098** |

### PCB（JB-Board V1.2）

| 项 | **值** |
|---|---|
| 板框 | **100 × 80 mm**，圆角 R2 |
| 厚度 / 表面处理 | **2.0 mm / 沉金** |
| 安装孔 | **4 × φ3.2（M3），距边 5mm** |
| 主控 | RobotDyn **Mega 2560 PRO MINI** |
| 主控座 | **2 × 24P 排母，行距 32.01mm** |
| **I²C 地址** | **电机 0x34 / AS5600 0x36 / MPU6050 0x68**（不冲突）|
| **I²C 上拉** | **4.7kΩ → 3.3V**（不是 5V！）|
| 上位机 UART | Serial1（D18/D19），**分压 上1kΩ / 下2kΩ = 3.33V** |
| 舵机 PWM | **D5**（OC3A）|
| **板上最大电流** | **2.3A**（7.4V 舵机支路）→ 走线 **1.5mm** |

### 电源树

```
板外：3S → 总开关 → 快断保险丝 → 反接保护(MBR1045) → 分三路
        ├─① 电机 11.1V  （不走板）
        ├─② DC-DC 5V  → 5V 端子  U1 → D3 → U7(PPTC 3.5A) → +5V   + C6 470µF
        └─③ DC-DC 7.4V → 7.4V 端子 U2 → D4 → U6(PPTC 3.5A) → +7.4V + C3 470µF
板上：AMS1117-3.3（输入 10µF / 输出 22µF / TAB 接 VOUT）
```

### 板上【不需要】留的（已确认）

| 不需要 | 原因 |
|---|---|
| 11.1V 输入端子 | 不走板 |
| 5V 输出端子（给 RDK X3）| 不走板 |
| TTS 模块座 | SX-TTS-E 模块 Micro USB 直插 X3 |
| 给 AS5600 的降压模块 | I²C 上拉改 3.3V 后不需要 |

### USB 分配（RDK X3 正好 3 个）

| 口 | 设备 |
|---|---|
| Type-A 3.0 | 摄像头 200万 |
| Type-A 2.0 #1 | 雷达 T-mini Plus |
| Type-A 2.0 #2 | SX-TTS-E（Micro USB）|
| — | **调试用 USB 扩展坞** |

---

## 1.2 全部有效决策（D1 ~ D34）

## 格式

| 字段 | 说明 |
|---|---|
| **ID** | D 编号，只增不改 |
| **决策** | 一句话说清 |
| **理由** | 为什么这么定（**关键**）|
| **被否的方案** | 考虑过但没选的，以及为什么 |
| **日期** | YYYY-MM-DD |

---

## 2026-10-05 · 设计输入阶段

| ID | 决策 | 理由 | 被否的方案 |
|---|---|---|---|
| **D1** | 主控用 **RobotDyn Mega 2560 PRO MINI** | 现有、4×UART / 6×中断 / 15×PWM / 54×IO，资源绰绰有余 | Arduino Uno/Nano（中断脚只剩 2 个，编码器就占满）|
| **D2** | **PCB = 100 × 80 mm**，圆角 R2，板厚建议 2.0 | ①卡立创 10×10cm **最便宜打样档** ②13 个端子排得下 ③电源区有散热间距 ④装得进 161 车宽 | 90×70（太挤，无调试余量）/ 110×85（超档位涨价）|
| **D3** | 主控座 = **2 × 24P 排母，行距 32.01mm** | RobotDyn 官方机械图：本体 38.00×52.00，排针行距 32.01 | — |
| **D4** | **I²C 地址**：电机 `0x34` / AS5600 `0x36` / MPU6050 `0x68` | 从前代 `JB_AprilTag_Tracker` 挖出实测值，**三者不冲突** | MPU6050 改 0x69（**不需要**，实测不撞）|
| **D5** | 上位机走 **Serial1 (D18/D19)**，Serial0 留给 USB 调试 | **插着 USB 也能收上位机指令**，调试期极方便 | 用 Serial0 和 USB 抢 |
| **D6** | I²C 经 **PCA9306** 转到 3.3V | 主控 5V，AS5600/MPU6050/电机模块都是 3.3V | 直连（会烧器件）|
| **D7** | **电源树三路独立**：电机 11.1V / 5V 逻辑 / 7.4V 舵机 | 隔离电机与舵机的开关噪声，避免拉垮主控 | 一路 5V 带全部（RDK X3 就 3A，会崩）|
| **D8** | **7.4V 从 11.1V 单独降**（板外模块）| 见「三个不能做」↓ | 从 5V 升压（5V 已 4.15A/5A，会崩）/ 取平衡头 2S（**电池失衡**）/ 11.1V 直供（**烧舵机**）|
| **D9** | **5V 模块选 ≥6A** | 负载 4.15A，5A 模块只剩 17% 余量 | 单块 5A（偏紧）|
| **D10** | **主干 2.0mm² 用 XT30/KF128；分支 ≤0.5mm² 用 XH2.54** | 2mm² 线径 1.6mm，**压不进 XH2.54**（AWG22~28，3A）| 全线 2mm²（接不上端子）|
| **D11** | **AS5600 用模块，不用裸片** | 它必须装在**主销轴线上**（与磁铁同轴），**离 PCB 60~80mm** | 照 V2.0 那样把裸片画在板上（**装不到位置，闭环废掉**）|
| **D12** | **主控 5V 脚由外部 Buck 直喂，绝不走 VIN** | 板载是线性稳压器：`(11.1−5)×4.8A = 29W` → 烧 | 走 VIN（会烧板）|
| **D13** | **TTS 放上位机（RDK X3）**，删掉 JQ8900 的 2×8P 座 | ①要读**任意中文**，JQ8900 只能播预存音频 ②软件 TTS 音质好得多 ③省 ¥50 + 省一大块板面积 | JQ8900（**能力不够**）/ XFS5152CE 下位机模块（音质差、多一条串口）|
| **D14** | **玻纤只打底板，不打印角** | FR4 是层压板，**层间强度远低于平面内**；羊角受弯矩+冲击会**沿层间劈裂** | 玻纤羊角（除非多层叠压+纤维交错+厚≥5mm）|
| **D15** | **信号线不加对地电容；电容只加在电源脚旁** | **I²C 总线电容上限 400pF**，加 100nF 直接超限 → 通信失败 | 每条信号线加电容（**会破坏 I²C**）|
| **D16** | **PPTC 只用于小电流分支；主回路用 Mini Blade 10A** | PPTC 在大电流下压降大、发热、反复动作后阻值永久升高 | 主回路用 PPTC（**你 V2.0 清单里已否决**，判断正确）|
| **D17** | PCB 上给 **TTS 模块留 4 个脚位**（5V/GND/TX/RX）+ 丝印 | **对冲 RDK X3 算力风险** —— 万一跑不动，焊模块就有救。成本≈0 | 不留（风险敞口）|

### 📌 D8 补充：7.4V 的三个「不能做」

| ✗ | 为什么 |
|---|---|
| 从 5V 升压到 7.4V | 5V 那路已 4.15A/5A，再抽 3.9A 去升压 → **崩** |
| 从 3S 平衡头取 2S（≈7.4V）| 只有一路放电 → **电池组失衡**，充电器报错，长期毁电池 |
| 11.1V 直供舵机 | TBSN-K15 是 **2S(7.4V)** 规格 → **烧** |

---

## 2026-10-05（下半场）· 电源与接口细化

| ID | 决策 | 理由 | 被否的方案 |
|---|---|---|---|
| **D18** | 反接保护用 **肖特基 MBR1045**（10A 45V，TO-220，**加散热片**）| 坏了是断路（安全）；总电流 7.7A 不算大，4.2W 加散热片能压住 | P-MOS（损耗仅 0.6W，但要多 3 个件）|
| **D19** | **I²C 上拉改到 3.3V**（原计划 5V）| **原理：I²C 是开漏输出，高电平全由外部上拉决定** → 上拉 3.3V，总线就是 3.3V，主控不会灌 5V。这样 **AS5600 可直接挂同一条总线** | 上拉 5V（**会烧 AS5600**，它没有电平转换）|
| **D20** | **删掉「给 AS5600 单独降压/转换的模块」** | D19 之后不需要了，省一个模块 + 一路线 | 单独 3.3V 模块 + 电平转换 |
| **D21** | **TTS 用 SX-TTS-E 模块，Micro USB 直插 RDK X3** | 模块自带 USB-UART + 功放 + 喇叭口，**完全脱离主板** → PCB 上连音频端子都不用留 | 板上留 TTS 座 / 走板子接线 |
| **D22** | **11.1V 和 RDK X3 的供电都不走板子** | 板上只需接已分好的 5V / 7.4V → **省掉 11.1V 端子和 5V 输出端子** | 全部从板上过 |
| **D23** | **保险丝**：主回路用**可换式**（5×20mm 玻璃管座，10A 慢断）；分路用**贴片**（慢断）| 主回路电流最大、最可能烧，要能现场换；分路电流小，贴片够用省空间 | 全部贴片（烧了要焊，调试期最不方便）/ 全部 Mini Blade（**立创封装难找**）|
| **D24** | LED 限流电阻 **220/330Ω → 1kΩ** | 现代 LED 2~5mA 够亮；原值 7.4V 那颗功耗 0.088W，0805 额定 0.125W 已到 70% | 保持原值 |
| **D25** | AMS1117 必须配 **输入 10µF + 输出 22µF**，且 **TAB 接 VOUT(3.3V)** | **无输出电容会自激振荡，3.3V 轨直接废**；TAB 是散热路径 | 不接电容（会振荡）/ TAB 悬空 |
| **D26** | 上位机 UART 分压：**上电阻 1kΩ / 下电阻 2kΩ** | `5V × 2k/(1k+2k) = 3.33V` ✓ | 反接（2k上/1k下 → 只有 1.67V，**低于 3.3V 器件的 2.0V 阈值**）|
| **D27** | **主控排母引脚以【实物】为准** | 白佳正对照实物核对过 | 照官方 pinout（可能与实物批次不同）|
| **D28** | **电机模块 和 MPU6050 模块 I²C 引脚均已做电平转换** | 白佳正验证过（所以 D19 改 3.3V 上拉后两者仍能工作）| — |

### 🔴 D23 补充：贴片保险丝选型要点

| 要点 | 说明 |
|---|---|
| **额定电流 ≥ 1.5× 正常工作电流** | 否则正常工作时误烧 |
| **必须选【慢断/延时型】** | 上电瞬间给电容充电是大电流浪涌，快断型会误动作 |
| **分断能力要够** | 11.1V 下短路电流可达几十 A |

| 支路 | 正常电流 | 保险丝额定 |
|---|---|---|
| 主回路 11.1V | 7.7A | **10A 慢断（可换式）** |
| 5V | 4.8A | 7.5A 慢断（贴片）|
| 7.4V 舵机 | 2.3A | 3.5A 慢断（贴片）|
| 3.3V | 0.05A | 0.5A（贴片）|

### 📌 D18 补充：选肖特基必须连带处理

1. ⚠️ **SS34 绝对不行**（SMA 封装 3A）→ 主回路 7.7A 要 **TO-220/D2PAK，≥10A**
2. ⚠️ **电池被吃掉 0.5V** → **低压保护阈值 +0.5V**（原 3.3V/cell=9.9V → 改测 10.4V）
3. 位置放【总开关之后、分路之前】

---

## 2026-10-05（收口）· 电源完成 + TTS 定版

| ID | 决策 | 理由 | 被否的方案 |
|---|---|---|---|
| **D29** | **USB 口就按 3 个用**：摄像头 / 雷达 / TTS 各占一个；**调试时用 USB 扩展坞** | RDK X3 正好 3 个 USB-A（3.0×1 + 2.0×2）。**调试用扩展坞比"改走串口"更省事**，不用动硬件 | 雷达改走串口 / 买带供电 Hub / 摄像头改 MIPI CSI（都留作后路）|
| **D30** | **TTS 模块定版：SX-TTS-E**（科大讯飞 **XFS5152CE** 核心）| 已确认规格：Micro USB（CH340 转串口）/ 板载 D 类功放 / **3W 4Ω 喇叭口** / 3.5mm 耳机座 / 支持 TTL·RS232·RS485 / 板载 LDO + 低 ESR 滤波 | 其他 TTS 模块 |
| **D31** | **过载/短路分工**：PPTC `ASMD1812-350-16V`（3.5A 保持 / 6A 跳闸 / 动作 4s）×2 做**过载保护**；**11.1V 入口用快断保险丝做短路保护**（板外，已就位）| **PPTC 动作要 4s，短路时来不及** → 短路必须靠快断保险丝；过载用 PPTC 可恢复，调试友好 | 全用 PPTC（短路不保）/ 全用保险丝（调试要换）|

### 📌 D30 补充：SX-TTS-E 使用要点（白佳正提供的规格图）

| 项 | 值 / 注意 |
|---|---|
| **核心芯片** | **XFS5152CE**（科大讯飞经典 TTS，中英文）|
| **上位机接口** | **Micro USB**（板载 CH340 转串口）→ **直插 RDK X3 的 USB 口** |
| **电源** | 板载 LDO；⚠️ **确认输入电压（3.3V 还是 5V）** |
| **喇叭** | ✅ **已定：直接买模块配套的「4Ω 3W 喇叭」**<br>⚠️ **白佳正原有的喇叭是 1Ω，不能用** —— 1Ω 时功放输出 12W（`3.46²/1`），是额定 3W 的 4 倍 → **烧功放**<br>（8Ω 也能响，但音量小一半）|
| **功放** | 板载 **D 类功放**，直推喇叭，不用外接 |
| **其他接口** | 3.5mm 耳机座 / TTL 串口（A 处引针）/ RS232 / RS485（带 TVS）/ SPI·IIC |
| **⚠️ 要配置的** | **通信开关** + **波特率配置**（板上有跳线/拨码，第一次用要设对）|

### 📌 D29 补充：USB 口分配表

| USB 口 | 设备 | 备注 |
|---|---|---|
| Type-A 3.0 | 摄像头（200万）| 走视觉 |
| Type-A 2.0 #1 | 雷达 T-mini Plus | 定位 |
| Type-A 2.0 #2 | **SX-TTS-E**（Micro USB）| 语音播报 |
| **—** | **调试用 USB 扩展坞** | 键鼠/U 盘/临时设备 |

**后路（若将来口不够）**：雷达改 UART（X3 的 40PIN）／摄像头改 MIPI CSI（X3 有 2 路）

---

## 2026-10-05（PCB 定版）

| ID | 决策 | 理由 |
|---|---|---|
| **D32** | **JB-Board V1.2 PCB 设计完成并通过全部检查** | DRC 无错 / 铺铜完整 / 网络全连通 / 反接保护极性核对无误 / U3U4 排母行距与 1 脚方向核对无误 |
| **D33** | **AS5600 端子不换规格**，改用**布局 + 丝印区分**防插错 | 白佳正决策：不增加物料种类，靠丝印（`AS5600 3.3V` vs `MOTOR 5V`）和位置区分 |
| **D34** | **舵机用 3P 排针**（电源在中间脚）| **正反插都安全** —— 反插只会不动作，不会烧（电源始终在中间）|

### 📌 D32 完成时的设计状态

```
板框   100 × 80 mm，圆角 R2，4× φ3.2 安装孔
布局   四分区（电源 / 数字 / 主控 / 端子）
铺铜   完整，无孤岛
DRC    无错误
丝印   端子名 + 电压 + 接口功能已标
```

### 📌 本阶段修掉的错误汇总（白佳正画板过程中）

| # | 错误 | 后果 |
|---|---|---|
| 1 | D1/D2 TVS 网络接反 | TVS 短路烧毁 |
| 2 | AMS1117 缺输出电容 | 自激振荡，3.3V 轨废 |
| 3 | AMS1117 TAB 悬空 | 散热路径断 |
| 4 | UART 分压接反（1.67V）| 通信不稳 |
| 5 | I²C 上拉在 5V | 会烧 AS5600 |
| 6 | LED 限流电阻偏小 | 到 0805 功耗 70% |
| 7 | 丝印 `MSP6050` 拼错 | → 改 `MPU6050` |

---

## 待定 / 未决

| ID | 议题 | 状态 |
|---|---|---|
| — | **拍摄距离与摄像头安装位置** | 等斜拍测试结果 |
| — | AS5600 与 TSSOP/模块形态最终确认 | 待购 |

## 附录：视觉实验结论（影响摄像头选型，不影响 PCB）

| 结论 | 数据 |
|---|---|
| **字高 ≈ 屏幕占画面宽 × 12%** | 98%→258px / 34%→80px / **15%→35px** |
| **门槛 25px → 占画面 ≥15% 就安全** | **最远 50cm 可行** |
| **摩尔纹** | 全部 3.6~4.0 → **不需要滤镜/全局快门** |
| **摄像头接口** | **USB 直插 RDK X3 → PCB 上不用留** |
| **曝光下限** | 全图均值 <16、亮像素 <3.4% → **完全不可用**，需手动固定曝光 |
| 已知局限 | 行距小时行数会数错（偏保守，不影响判定）|

---

# 第二章 · ⚠️ 已废弃 / 被否的方案（仅备查，**不要照着做**）

> **以下内容是设计过程中【考虑过但放弃】的方案，以及【踩过的坑】。**
> **保留它们是为了以后回看时知道"为什么没选那条路"，不是施工依据。**
>
> **⚠️ 如果你在这里看到某个做法，先回到第一章确认为什么不用它。**

## 2.1 被否的电源/保护方案

| 被否方案 | 为什么不用 |
|---|---|
| 从 5V 升压到 7.4V | 5V 那路已 4.15A/5A，再抽 3.9A 去升压 → 崩 |
| 从 3S 平衡头取 2S（≈7.4V）| 只有一路放电 → **电池组失衡**，充电器报错，长期毁电池 |
| 11.1V 直供舵机 | TBSN-K15 是 **2S(7.4V)** 规格 → **烧** |
| 主电路用 PPTC 做短路保护 | **PPTC 动作要 4s，短路来不及** → 短路必须靠快断保险丝 |
| 主控 5V 走 VIN | 板载是线性稳压器，`(11.1−5)×4.8A = 29W` → **烧** |
| AMS1117 不接输出电容 | **会自激振荡，3.3V 轨直接废** |
| AMS1117 TAB 悬空 | TAB 就是 VOUT，悬空则散热路径断 |

## 2.2 被否的接口/器件方案

| 被否方案 | 为什么不用 |
|---|---|
| **I²C 上拉到 5V** | **会烧 AS5600**（它是裸器件，无电平转换）→ 改 3.3V |
| **AS5600 单独加降压/电平转换模块** | 上拉改 3.3V 后不需要 |
| **信号线加对地电容滤波** | **I²C 总线电容上限 400pF**，加 100nF 直接超限 → 通信失败 |
| **AS5600 用裸片画在板上** | 它必须装在**主销轴线上**（离板 60~80mm），画在板上装不到位置 |
| **照 V2.0 用 2k上/1k下分压** | 只有 1.67V，低于 3.3V 器件的 2.0V 阈值 → 改 1k上/2k下 |
| **JQ8900 播预存音频** | 要朗读**任意中文**（读显示屏），能力不够 → 改 TTS 方案 |
| **TTS 放板上** | SX-TTS-E 模块 Micro USB 直插 X3 更干净，板上留座浪费面积 |
| **电机/编码器直连（PWM+方向+编码器 10 个脚）** | 改走 I²C，省 10 个引脚 |
| **Mini Blade 汽车保险丝** | 立创封装难找 → 改 5×20mm 玻璃管座 |

## 2.3 被否的机械/材料方案

| 被否方案 | 为什么不用 |
|---|---|
| **玻纤打印角（羊角）** | FR4 是层压板，**层间强度远低于平面内**；羊角受弯矩+冲击会**沿层间劈裂** → 只打底板 |
| 把 SX-TTS-E 接到 1Ω 喇叭 | 模块设计 4Ω/3W；接 1Ω 时功放输出 12W（`3.46²/1`）= 额定 3W 的 **4 倍** → 烧功放 |

## 2.4 被否的视觉方案

| 被否方案 | 为什么不用 |
|---|---|
| 用 JQ8900 播固定语句 | 需求是读**显示屏上的任意中文** |
| 测层面：加低通滤镜 / 换全局快门 | **实测不需要**（摩尔纹 3.6~4.0，远低于阈值 8）|
| 摄像头走板上接口 | USB 直插 X3 即可，**PCB 上不用留** |

## 2.5 实施过程中踩过的坑（错误示范）

| 坑 | 后果 |
|---|---|
| **D1/D2 TVS 网络接反**（5V 的接到 7.4V）| **7.4V > 5V 击穿 → TVS 短路烧毁** |
| **LED 限流用 220Ω/330Ω** | 7.4V 那颗功耗 0.088W，0805 额定 0.125W → 到 **70%** |
| 屏幕区域检测用"最大亮连通域" | 会被**白衣服/白墙**骗到（视觉实验踩的）|
| 摩尔纹指标用 `FFT 99.95分位/中位数` | **结果是反的** —— 无摩尔纹 45.1，有摩尔纹反而 28~30 |
| 行分割用"水平投影 + 固定阈值" | **斜拍/透视下失效**（文字 y 坐标两端不同，投影被抹平）|

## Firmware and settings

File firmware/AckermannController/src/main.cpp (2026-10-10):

// ============================================================
// main.cpp —— 阿克曼底盘下位机主程序
//
// 【整体架构】
//
//   RDK X3（上位机）                   Mega2560（下位机）
//   ┌──────────────┐   Serial1    ┌──────────────────────┐
//   │ 视觉 / 雷达   │ ──────────→  │ UartProtocol 解析指令 │
//   │ 决策         │  v, ω        │        ↓             │
//   └──────────────┘              │ AckermannDrive       │
//                                 │   ├→ ServoSteering → 舵机(D5)
//                                 │   └→ MotorDriverI2C → 电机模块(I²C 0x34)
//                                 └──────────────────────┘
//
// 【控制流】
//   50Hz 主循环：
//     ① 解析串口（收上位机指令）
//     ② 检查指令超时（断了就停车 —— 安全兜底）
//     ③ 下发到执行器
//
// 【为什么要有超时保护】
//   如果上位机崩溃 / 线松了，下位机不能继续执行最后的指令 ——
//   那车会一直往前冲。所以超过 CMD_TIMEOUT_MS 没收到新指令就停车。
//   ★ 这是机器人安全的基本要求，不能省。
// ============================================================

#include <Arduino.h>
#include "AckermannConfig.h"
#include "MotorDriverI2C.h"
#include "UartProtocol.h"
#include "ServoSteering.h"
#include "AckermannDrive.h"

// ---------- 全局对象 ----------
static MotorDriverI2C   g_motor;
static ServoSteering    g_steer;
static AckermannDrive   g_drive(g_motor, g_steer);

static unsigned long    g_lastCmdMs   = 0;      // 上次收到指令的时刻
static bool             g_wasTimeout  = false;  // 超时状态（用于只打印一次）

// ---------- 打印辅助 ----------
static void printState(float v, float steerDeg, int8_t cmd)
{
    DEBUG_SERIAL.print(F("[状态] v="));
    DEBUG_SERIAL.print(v, 2);
    DEBUG_SERIAL.print(F("m/s  steer="));
    DEBUG_SERIAL.print(steerDeg, 1);
    DEBUG_SERIAL.print(F("°  cmd="));
    DEBUG_SERIAL.print(cmd);
    DEBUG_SERIAL.print(F("  R="));
    DEBUG_SERIAL.print(g_drive.getTurnRadius(), 0);
    DEBUG_SERIAL.println(F("mm"));
}

// ============================================================
void setup()
{
    // ① 调试串口（USB）
    DEBUG_SERIAL.begin(115200);
    delay(200);
    DEBUG_SERIAL.println();
    DEBUG_SERIAL.println(F("============================================"));
    DEBUG_SERIAL.println(F(" JB 阿克曼底盘 · 下位机 v1.0"));
    DEBUG_SERIAL.println(F("============================================"));

    // ② 上位机串口
    UartProtocol::begin();

    // ③ 电机驱动（I²C）
    g_motor.begin();
    g_motor.stop();

    // ④ 转向舵机
    g_steer.begin();

    // ⑤ 运动控制
    g_drive.begin();

    g_lastCmdMs = millis();

    DEBUG_SERIAL.println(F("[系统] 初始化完成，等待上位机指令..."));
    DEBUG_SERIAL.println(F("============================================"));
}

// ============================================================
void loop()
{
    // ── ① 解析串口（非阻塞，每圈都调）──
    UartProtocol::update();

    // ── ② 收到新指令？──
    if (UartProtocol::hasNewCommand()) {
        float v  = UartProtocol::getLinearX();
        float wz = UartProtocol::getAngularZ();

        g_drive.setVelocity(v, wz);
        g_lastCmdMs  = millis();
        g_wasTimeout = false;

        static unsigned long lastPrint = 0;
        if (millis() - lastPrint > 200) {          // 限流打印，别刷屏
            printState(v, g_drive.getSteerDeg(), g_drive.getMotorCmd());
            lastPrint = millis();
        }
    }

    // ── ③ 指令超时保护 ──
    //   ★ 关键安全机制：上位机断了必须停车
    if (millis() - g_lastCmdMs > CMD_TIMEOUT_MS) {
        if (!g_wasTimeout) {
            DEBUG_SERIAL.println(F("[安全] ⚠️ 指令超时，自动停车！"));
            g_drive.stop();
            g_wasTimeout = true;
        }
    }

    // ── ④ 固定周期 ──
    //   用 delay 实现（简单）；如果要更准可以用 millis 做时间片
    delay(1000 / CONTROL_HZ);
}

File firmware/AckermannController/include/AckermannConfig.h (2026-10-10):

#pragma once
// ============================================================
// AckermannConfig.h —— 阿克曼底盘的全部可调参数
//
// ★ 所有"魔数"集中在这里，改参数只改这一个文件。
//   这是嵌入式项目的基本纪律：不要把数字散落在代码里。
// ============================================================

// ---------- 通信 ----------
#define UART_BAUDRATE   115200        // 上位机串口波特率
#define UART_SERIAL     Serial1       // 上位机接 Serial1 (D18=TX1, D19=RX1)
                                      // ★ Serial0 留给 USB 调试 —— 插着 USB 也能收指令
#define DEBUG_SERIAL    Serial        // 调试输出（USB）

// ---------- 舵机（转向）----------
// 舵机接 D5（OC3A，独立定时器，不被其他 PWM 干扰）
#define SERVO_PIN       5

// ★ 舵机脉宽标定表（来自 档案/23-当前基准-最终版.md）
//   左轮转角 → 脉宽（微秒）
//   注意：这是【实测标定值】，不是线性推算的
#define SERVO_US_LEFT_20  1709        // 左轮 -20°（=右转）
#define SERVO_US_LEFT_10  1604
#define SERVO_US_CENTER   1500        // 中位（直行）★ 关键基准
#define SERVO_US_LEFT_P10 1391        // 左轮 +10°
#define SERVO_US_LEFT_P20 1275
#define SERVO_US_LEFT_P35 1098        // 左轮 +35°（最大左转）

#define SERVO_ANGLE_MAX   35.0f       // 机械最大转角（度）
#define SERVO_US_MIN      1000        // 脉宽安全下限（防堵转烧舵机）
#define SERVO_US_MAX      2000        // 脉宽安全上限

// ---------- 底盘几何 ----------
#define WHEEL_DIAMETER_MM   65.0f     // 车轮直径（mm）★ 装好后实测再改
                                      // ⚠️ 用卷尺量轮子外径，或在地上滚一圈量距离/π
#define WHEEL_BASE_MM       200.0f    // 轴距 L（mm）—— 档案基准
#define TRACK_WIDTH_MM      237.0f    // 前轮距（mm）
#define MAX_SPEED_MS        1.5f      // 最大线速度（m/s）—— 保守值

// ---------- 电机 ----------
// hiwonder 四路模块的速度范围约 -50 ~ +50
#define MOTOR_SPEED_MAX     50
// 驱动方式：1 = 后驱（用 M3/M4，阿克曼标准）
//           2 = 四驱（M1~M4 同速，转向时会滑）
#define DRIVE_MODE          1

// ---------- 控制周期 ----------
#define CONTROL_HZ          50        // 控制频率（Hz）→ 周期 20ms
#define CMD_TIMEOUT_MS      500       // 上位机指令超时（ms）→ 超时自动停车

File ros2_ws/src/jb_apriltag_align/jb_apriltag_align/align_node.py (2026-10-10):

#!/usr/bin/env python3
# -*- coding: utf-8 -*-
"""
JB 阿克曼 · 最小视觉闭环（AprilTag 对准）
================================================

【这个节点实现什么闭环】

    摄像头 ─→ AprilTag 检测 ─→ 算误差 ─→ P 控制 ─→ 串口 ─→ 下位机 ─→ 车动
       ↑                                                              │
       └──────────────────── 车动导致图像变化 ←──────────────────────┘

    这就是最基础的【视觉伺服】（visual servoing）闭环。

【为什么选 AprilTag 而不是 SLAM 做最小闭环】

    目标：把车开到标签正前方并停住（"精准进框"）。

    SLAM（gmapping）：
      输出【全局位姿】+ 地图 → 适合"从 A 开到 B"
      需要：里程计（odom）+ 雷达 + 建图时间
      ⚠️ 现在 AS5600 还没到，里程计做不了 → SLAM 暂时跑不起来

    AprilTag 视觉伺服：
      输出【相对目标的横向/纵向误差】→ 直接用于对准
      需要：只有摄像头（已有）
      ✅ 今天就能跑通

    ★ 结论：最小闭环 = AprilTag 视觉伺服。SLAM 是后续加分项。

【控制律（P 控制器）】

    图像/位姿误差 → 速度指令：

      横向误差 ex (m) :  车偏左/偏右多少
        → 角速度 ω = Kp_yaw_ · ex        （偏了就打方向）
        → ⚠️ 阿克曼不能原地转，所以 ω 只在前进时有意义

      纵向误差 ez (m) :  离标签还有多远
        → 线速度 v = Kp_dist · ez        （远了就快，近了就慢）
        → 限幅到 [v_min, v_max]

    为什么要限幅？
      · v 太小：电机死区，走不动 → 设 v_min
      · v 太大：冲过头，来不及停 → 设 v_max
      · 距离小于 stop_dist 时 v = 0（到位停车）

【为什么用 P 而不是 PID】

    视觉伺服的误差本身就在快速变化（车在动），
    积分项 I 容易累积导致过冲；微分项 D 对图像噪声敏感。
    P 控制够用，而且调参简单（只有 2 个参数）。
    ★ 先跑通 P，不够再加 D。

【串口协议】（与下位机 UartProtocol.cpp 对应）

    发送:  "V,<linearX>,<angularZ>\n"
      linearX  : m/s    前进速度（负=后退）
      angularZ : rad/s  角速度（正=左转）
    下位机会自动把 ω 反算成前轮转角：δ = atan(ω·L/v)

【跑法】
    ros2 run jb_apriltag_align align_node \
      --ros-args -p port:=/dev/ttyS0 -p tag_id:=0 -p target_dist:=0.5
"""

import rclpy
from rclpy.node import Node
from sensor_msgs.msg import Image
from geometry_msgs.msg import Twist          # ★ 标准速度消息
from std_msgs.msg import String
from cv_bridge import CvBridge
from rclpy.qos import QoSProfile, ReliabilityPolicy, HistoryPolicy
import cv2
import math
import time
import numpy as np

try:
    import serial                              # pyserial
    HAS_SERIAL = True
except ImportError:
    HAS_SERIAL = False


class AlignNode(Node):

    def __init__(self):
        super().__init__('jb_align_node')

        # ══════════ 参数 ══════════
        # 摄像头
        self.declare_parameter('camera_topic', '/camera/image_raw')
        # AprilTag
        self.declare_parameter('tag_id', 0)          # 只跟这个 ID 的标签
        self.declare_parameter('tag_size', 0.05)     # 标签实际边长（米）
        # ★ 相机内参：RDK X3 + 200万摄像头的近似值
        #   ⚠️ 正式用必须自己标定（见 README）
        self.declare_parameter('fx', 700.0)
        self.declare_parameter('fy', 700.0)
        self.declare_parameter('cx', 640.0)
        self.declare_parameter('cy', 360.0)
        # 目标位置
        self.declare_parameter('target_dist', 0.5)   # 想停在离标签多远（米）
        self.declare_parameter('stop_dist', 0.45)    # 小于这个距离就停
        # 控制增益
        self.declare_parameter('kp_dist', 1.2)       # 距离 → 线速度
        self.declare_parameter('kp_yaw', 2.0)        # 横向误差 → 角速度
        self.declare_parameter('v_min', 0.12)        # 最小线速度（克服死区）
        self.declare_parameter('v_max', 0.5)         # 最大线速度
        self.declare_parameter('w_max', 1.2)         # 最大角速度
        # 串口
        self.declare_parameter('port', '/dev/ttyS0')
        self.declare_parameter('baudrate', 115200)
        self.declare_parameter('send_hz', 20.0)      # 串口发送频率

        self.tag_id      = self.get_parameter('tag_id').value
        self.tag_size    = self.get_parameter('tag_size').value
        self.fx          = self.get_parameter('fx').value
        self.fy          = self.get_parameter('fy').value
        self.cx          = self.get_parameter('cx').value
        self.cy          = self.get_parameter('cy').value
        self.target_dist = self.get_parameter('target_dist').value
        self.stop_dist   = self.get_parameter('stop_dist').value
        self.kp_dist     = self.get_parameter('kp_dist').value
        self.kp_yaw      = self.get_parameter('kp_yaw').value
        self.v_min       = self.get_parameter('v_min').value
        self.v_max       = self.get_parameter('v_max').value
        self.w_max       = self.get_parameter('w_max').value

        # ══════════ AprilTag 检测器 ══════════
        # ★ 优先用 pupil_apriltags（更准），没有就退回 cv2.aruco
        self.detector = None
        self.detector_type = None
        try:
            from pupil_apriltags import Detector
            self.detector = Detector(
                families='tag36h11',      # 最常用的族
                nthreads=2,
                quad_decimate=2.0,        # 降采样加速（X3 算力有限）
                quad_sigma=0.0,
                refine_edges=1,
                decode_sharpening=0.25,
                debug=0,
            )
            self.detector_type = 'pupil'
            self.get_logger().info('✅ 用 pupil_apriltags 检测')
        except ImportError:
            # ── 退回 OpenCV 自带（不需要额外装包）──
            # ⚠️ OpenCV 4.7 起 aruco API 大改：
            #    旧 (<=4.6): Dictionary_get() + DetectorParameters_create() + detectMarkers()
            #    新 (>=4.7): getPredefinedDictionary() + DetectorParameters() + ArucoDetector
            #    两套 API 不兼容，必须按版本分支！
            if not hasattr(cv2, 'aruco'):
                self.get_logger().error('❌ 没有 AprilTag 检测器！装 pupil-apriltags 或 opencv-contrib')
                raise RuntimeError('no apriltag detector')

            cv_ver = tuple(int(x) for x in cv2.__version__.split('.')[:2])
            if cv_ver >= (4, 7):
                # ── 新 API ──
                d = cv2.aruco.getPredefinedDictionary(cv2.aruco.DICT_APRILTAG_36h11)
                p = cv2.aruco.DetectorParameters()
                det = cv2.aruco.ArucoDetector(d, p)
                self.detector = ('new', det)
                self.get_logger().info(f'✅ 用 cv2.aruco 新 API 检测 (OpenCV {cv2.__version__})')
            else:
                # ── 旧 API ──
                d = cv2.aruco.Dictionary_get(cv2.aruco.DICT_APRILTAG_36h11)
                p = cv2.aruco.DetectorParameters_create()
                self.detector = ('old', (d, p))
                self.get_logger().info(f'✅ 用 cv2.aruco 旧 API 检测 (OpenCV {cv2.__version__})')
            self.detector_type = 'aruco'

        # ══════════ 订阅摄像头 ══════════
        # ★ 传感器话题用 BEST_EFFORT（和雷达一样的坑）
        qos = QoSProfile(
            reliability=ReliabilityPolicy.BEST_EFFORT,
            history=HistoryPolicy.KEEP_LAST,
            depth=1,
        )
        cam_topic = self.get_parameter('camera_topic').value
        self.sub = self.create_subscription(Image, cam_topic, self.on_image, qos)
        self.bridge = CvBridge()

        # ══════════ 发布（调试用）══════════
        # 把算出来的速度也发成 Twist，方便用 rqt 看 / 录 bag
        self.pub_cmd = self.create_publisher(Twist, '/cmd_vel', 10)
        self.pub_state = self.create_publisher(String, '/align_state', 10)
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

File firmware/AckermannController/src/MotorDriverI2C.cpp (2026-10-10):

#include "MotorDriverI2C.h"
// MotorDriverI2C.h：电机驱动模块接口

#include <Wire.h>
// Wire.h：Arduino I²C 通信库


namespace
{
    constexpr uint8_t I2C_ADDR = 0x34;
    // I2C_ADDR：驱动板 I²C 从机地址

    constexpr uint8_t MOTOR_TYPE_ADDR = 0x14;
    // MOTOR_TYPE_ADDR：电机类型寄存器

    constexpr uint8_t MOTOR_ENCODER_POLARITY_ADDR = 0x15;
    // MOTOR_ENCODER_POLARITY_ADDR：编码器方向极性寄存器

    constexpr uint8_t MOTOR_FIXED_SPEED_ADDR = 0x33;
    // MOTOR_FIXED_SPEED_ADDR：四路闭环固定速度寄存器

    constexpr uint8_t MOTOR_ENCODER_TOTAL_ADDR = 0x3C;
    // MOTOR_ENCODER_TOTAL_ADDR：四路编码器累计脉冲寄存器

    constexpr int8_t M1_DIR = 1;
    constexpr int8_t M2_DIR = -1;
    constexpr int8_t M3_DIR = -1;
    constexpr int8_t M4_DIR = 1;
}


// ============================================================
// 初始化
// ============================================================

void MotorDriverI2C::begin()
{
    Wire.begin();
    // Wire.begin()：初始化 Mega2560 I²C 主机

    uint8_t motorType = 3;
    // 3：JGB37_520-12V-110RPM，90:1 编码电机

    Wire.beginTransmission(I2C_ADDR);
    // beginTransmission()：开始向驱动板发送数据

    Wire.write(MOTOR_TYPE_ADDR);
    // write()：发送目标寄存器地址

    Wire.write(motorType);
    // write()：发送电机类型

    Wire.endTransmission();
    // endTransmission()：结束 I²C 写操作


    uint8_t encoderPolarity = 0;
    // 0：默认编码器方向极性

    Wire.beginTransmission(I2C_ADDR);

    Wire.write(MOTOR_ENCODER_POLARITY_ADDR);

    Wire.write(encoderPolarity);

    Wire.endTransmission();
}


// ============================================================
// 设置四路电机速度
// ============================================================

void MotorDriverI2C::setSpeed(
    int8_t motor1,
    int8_t motor2,
    int8_t motor3,
    int8_t motor4
)
{
    int8_t speed[4] =
    {
        motor1,
        motor2,
        motor3,
        motor4
    };
    // speed[4]：保存四路电机目标速度


    Wire.beginTransmission(I2C_ADDR);
    // 开始 I²C 通信

    Wire.write(MOTOR_FIXED_SPEED_ADDR);
    // 指定 0x33：固定速度寄存器

    Wire.write(
        reinterpret_cast<uint8_t *>(speed),
        4
    );
    // reinterpret_cast()：把 int8_t 数组转换成字节数组
    // 发送 4 个速度值


    Wire.endTransmission();
    // 结束 I²C 通信
}


// ============================================================
// 停止
// ============================================================

void MotorDriverI2C::stop()
{
    setSpeed(
        0,
        0,
        0,
        0
    );
    // setSpeed()：四个电机目标速度全部设为 0
}


// ============================================================
// 读取编码器
// ============================================================

bool MotorDriverI2C::readEncoder(
    int32_t encoder[4]
)
{
    Wire.beginTransmission(I2C_ADDR);
    // 开始 I²C 通信

    Wire.write(MOTOR_ENCODER_TOTAL_ADDR);
    // 指定 0x3C：编码器累计脉冲寄存器

    if (Wire.endTransmission(false) != 0)
    {
        // false：保持 I²C 总线连接，准备读取

        return false;
        // false：通信失败
    }


    uint8_t received =
        Wire.requestFrom(
            I2C_ADDR,
            (uint8_t)16
        );
    // requestFrom()：请求读取 16 字节
    // 4 个 int32_t = 16 字节


    if (received != 16)
    {
        return false;
        // 数据长度不正确
    }


    for (int motor = 0; motor < 4; motor++)
    {
        // motor：当前读取的电机编号

        encoder[motor] =
            (int32_t)Wire.read() |
            ((int32_t)Wire.read() << 8) |
            ((int32_t)Wire.read() << 16) |
            ((int32_t)Wire.read() << 24);
        // read()：读取一个字节
        // <<：把字节移动到对应的位置
        // |：组合成完整的 int32_t
    }


    return true;
    // true：编码器读取成功
}

void MotorDriverI2C::setChassisSpeed(int8_t left, int8_t right)
{
    MotorDriverI2C::setSpeed(
        left  * M1_DIR,
        left  * M2_DIR,
        right * M3_DIR,
        right * M4_DIR
    );
}

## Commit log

2026-10-05 feat: 初始化阿克曼医疗机器人项目
    ## 项目定位
    华北五省机器人大赛 · 智慧医疗服务机器人（专项赛道）
    一台可无限复用的阿克曼底盘
    ## 新增
    - README.md 项目总览 + 任务链 + 进度
    - docs/01-比赛任务与规则.md 任务链 + 硬性规则（含三条'正好卡线'）
    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
    [底板.STL, 羊角转向节.STL, 装配 - 底板-1.STL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]
2026-10-05 docs: 补充 PCB 尺寸决策与布局草图
    - hardware/electronics/PCB布局草图-100x80.png
    - hardware/electronics/01-设计输入.md（含 PCB 尺寸决策第六节）
2026-10-05 docs: 确认 I²C 地址不冲突 + 补可复用资产清单
    从前代项目 JB_AprilTag_Tracker 挖出实测可用的接口：
    - hiwonder 电机模块 I²C 地址 = 0x34（AS5600=0x36, MPU6050=0x68，三者不冲突）
    - 寄存器表：0x14 电机类型 / 0x15 编码器极性 / 0x33 速度 / 0x3C 编码器累计
    - 速度范围 ±50，编码器读 16 字节（4× int32 小端）
    - 可复用：MotorDriverI2C / UartProtocol / MPU6050 / Scan_IIC
    - 新增 AckermannDrive 接口设计（与 DifferentialDrive 签名一致，上位机零改动）
2026-10-05 docs: 补可复用资产清单 + AckermannDrive 接口设计
    从前代项目 JB_AprilTag_Tracker 挖出实测可用资产：
    - MotorDriverI2C / UartProtocol / MPU6050 / Scan_IIC 全部可直接抄
    - I²C 地址确认：电机 0x34 / AS5600 0x36 / MPU6050 0x68（互不冲突）
    - AckermannDrive 接口与 DifferentialDrive 签名一致 → 上位机零改动
    - 补充阿克曼物理限制：不能原地转向
2026-10-05 feat(V1.2): BOM（立创货号版）
    ## 内容
    - hardware/BOM-V1.2.md 完整 BOM，分 A/B/C 三组
    - hardware/BOM-V1.2.csv 可导入对照的 CSV
    ## A 组：直接复用 V1.1 已验证货号（12 项）
    470uF C2873966 / 100nF C5137467 / 10uF C6119887 / 22uF C11366
    10k C2930231 / 2k C2907315 / 0R C17477 / LED C965812
    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
    [BOM-V1.2.csv]
2026-10-05 docs(V1.2): 电源树定案（三路独立）+ 线径端子匹配表
    ## 电源树
    3S 11.1V → 总开关+总保险丝(10A)
    ├ ① 电机直供 11.1V（hiwonder 模块）
    ├ ② DC-DC 5V ≥6A（RDK X3 3A + 主板 1.2A）
    └ ③ DC-DC 7.4V ≥5A（主板→舵机端子，板上直转）
    ## 7.4V 为何单独一路（三个不能做）
    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
2026-10-05 feat(experiments): 拍屏 OCR 可行性验证例程
    ## 背景
    比赛要求读【显示屏上的中文】-> 必须走 OCR + TTS。
    拍屏幕有三个物理坑（摩尔纹/刷新条纹/过曝），比选什么 OCR 引擎重要得多。
    这个实验在画板前把地基验证掉，成本 10 分钟。
    ## 实测硬件事实
    - /dev/video0 最高 1280x720 （不够 OCR）
    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
2026-10-05 fix(experiments): 修 analyze.py 三处 bug —— 实测首张照片从假阴性变正确
    ## 白佳正的第一次实测
    拍手机屏幕显示「化验区忙碌中 / 需等待8秒」，1920x1080。
    原脚本判『❌ 不能 OCR』，但肉眼看图完全清晰 —— 是我的 bug。
    ## 修的三个 bug
    1. **屏幕外黑背景污染** —— 外接矩形包进四角黑背景，
    黑背景反相二值化后全变前景 -> 文字行连成一整块 412px
    修：新增 find_screen()（Otsu + 最大亮连通域）+ clean_screen_bg()
    2. **预处理把文字擦掉** —— 用「亮连通域」当 mask 会把屏幕内的文字（洞）填成底色
    修：改用 **外轮廓填充**（RETR_EX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
2026-10-05 fix(experiments): 修 4 处检测 bug + 如实记录已知局限
    ## 白佳正的 3 张新照片（不同距离）
    原脚本全部误判，逐层排查修了 4 个问题：
    1. **白衣服被当成屏幕** —— find_screen 用最大亮连通域，
    但画面里有更亮更大的白衣服。
    修：改用三合一判据（亮 >=90 + 标准差 >=30 + 暗笔画 1~50%），评分=均值x标准差。
    实测：屏幕 227x129 均值226.8/标准差59.5/暗笔画8.0%
    屏幕 373x242 均值170.7/标准差110.6/暗笔画31.5%
    白衣服：亮但标准差小 -> 被排除
    2. **过曝指标算错** —— 我把过曝算到屏幕区域内，
    但屏幕是自发光的，白底本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
2026-10-05 docs(experiments): 记录工具能力边界与已知局限
    诚实交代：行距很小时会把两行合成一行，字高偏大。
    但偏保守（只会把能说成勉强，不会把不能说成能），可接受。
    兜底：--roi 手动框单行。
2026-10-05 fix(experiments): 行检测改为水平膨胀法 —— 7 张实拍全部行数修正
    ## 白佳正的反馈（关键）
    1. 照片只有 2 行（第一行 6 字、第二行 5 字）—— 我 7 张全数错
    2. 手抖那张我没识别出来
    3. 前几张是手动调曝光 -> 工具该给曝光评估
    ## 根因
    投影法在【斜拍/透视】下失效：文字 y 坐标在屏幕两端不同，
    水平投影被抹平，行间谷值消失。
    ## 修法
    改用【水平膨胀 + 连通域】（经典文本行分割）：
    估计字宽 -> 水平膨胀把同行的字连成扁长条 -> 连通域取行（要求宽高比 >2.2）
    -> 6/7 张正确识别为 2 行
    ## 修正后（7 组距离测试）
    | 屏幕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
2026-10-06 docs: 建决策日志 + 记录反接保护议题
    ## 新增 docs/00-决策日志.md
    把本次会话产生的 17 条设计决策全部落档（D1~D17），每条含：
    ID / 决策 / 理由 / 被否的方案 / 日期
    目的：三个月后回来看板子，能知道为什么当初这么画。
    ## 已记录的决策（D1~D17）
    D1 主控 Mega 2560 PRO MINI
    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
2026-10-06 docs: 固化 D18~D28（电源与接口细化决策）
    D18 反接保护用肖特基 MBR1045（10A TO-220 + 散热片）
    D19 I2C 上拉改 3.3V（开漏原理，主控不会灌 5V）-> AS5600 可直挂同总线
    D20 删掉给 AS5600 单独降压的模块
    D21 TTS 用 SX-TTS-E 模块 Micro USB 直插 RDK X3（脱离主板）
    D22 11.1V 和 RDK X3 供电都不走板子 -> 省两个端子
    D23 保险丝：主回路可换式(5x20玻璃管 10A慢断)，分路用贴片慢断
    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
2026-10-06 docs: 定版 D29~D31（USB分配 / TTS模块 / 过载短路分工）
    D29 USB 就按 3 个用（摄像头/雷达/TTS），调试用扩展坞
    D30 TTS 定版 SX-TTS-E（XFS5152CE 核心，Micro USB，板载D类功放，3W 4Ω喇叭口）
    D31 过载用 PPTC(3.5A/4s) + 短路用快断保险丝（11.1V入口，板外已就位）
    补充要点：
    - SX-TTS-E 要用 4Ω 喇叭（接口标 3W 4R），8Ω 音量减半
    - 模块有通信开关 + 波特率配置，第一次用要设对
    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
2026-10-06 docs: D30 补充 —— 喇叭定版用配套 4Ω 3W
    白佳正原有喇叭是 1Ω，接 SX-TTS-E 会烧功放：
    模块 3W@4Ω -> 输出约 3.46V
    接 1Ω 时 P = 3.46²/1 = 12W = 额定 3W 的 4 倍
    -> 直接买模块配套的 4Ω 3W 喇叭
2026-10-07 docs: PCB 定版 D32~D34
    D32 JB-Board V1.2 PCB 设计完成并通过全部检查
    （DRC无错/铺铜完整/网络全连通/反接保护极性核对无误/排母核对无误）
    D33 AS5600 端子不换规格，改用布局+丝印区分防插错
    D34 舵机用 3P 排针（电源在中间脚）→ 正反插都安全
    附：本阶段修掉的 7 个错误清单
2026-10-07 docs: 决策日志重排 —— 正确在前 / 废弃在后
    ## 白佳正要求
    把之前的所有错误抉择删掉或排到后面，把正确的写到前面，以免看的人做错
    ## 新结构
    第一章 · ✅ 当前有效（施工只看这一章）
    1.1 关键参数速查表（整车几何 / 舵机脉宽 / PCB / 电源树 / USB分配）
    1.2 全部有效决策 D1~D34
    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
2026-10-09 feat(ros2_ws): 摄像头测试包 jb_camera_test（真机验证通过）
    ## 新增 ros2_ws/ 工作区
    本机写代码 + 详细中文注释 -> scp 到 RDK X3 编译运行
    ## jb_camera_test 包
    - camera_test.py 发布端：打开 USB 摄像头，发 /camera/image_raw
    - camera_sub.py 订阅端：统计帧率 + 端到端延迟 + 按需存图
    - launch/ 一次启动两个节点
    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
2026-10-09 feat(ros2_ws): 雷达测试包 jb_lidar_test（真机跑通 + QoS 坑记录）
    ## 新增 jb_lidar_test 包
    - lidar_test.py 订阅 /scan，打印点数/角度/最近障碍/前方预警
    含 LaserScan 消息结构的完整中文注释（学这个）
    - lidar_safety.py 分左前/正前/右前扇区，发布 /lidar_safety (CLEAR/SLOW/STOP)
    针对阿克曼特性（只能前开+打方向）设计
    - launch/ 一键起驱动+测试+安全三个节点
    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
2026-10-10 feat(firmware): 阿克曼下位机固件（基于 AprilTag-Tracker 改造）
    ## 复用（未改）
    - MotorDriverI2C.h/cpp hiwonder 四路电机 I2C 驱动（0x34）
    - UartProtocol.h/cpp cmd_vel 风格串口协议
    - AckermannConfig.h 所有参数集中（舵机标定/几何/限幅/超时）
    - ServoSteering 舵机控制：标定表[-20~+35] + 线性插值 + 双重限幅
    - AckermannDrive ★ 阿克曼运动学：ω → δ 反算 δ=atan(ωL/v)
    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
2026-10-10 feat(ros2_ws): 最小视觉闭环 jb_apriltag_align（AprilTag 视觉伺服）
    ## 闭环结构
    摄像头 -> AprilTag 检测 -> P 控制 -> 串口 -> 下位机 -> 车动 -> 回到摄像头
    ## 为什么用视觉伺服而不是 SLAM 做最小闭环
    - 视觉伺服：输出【相对目标误差】，只需摄像头，今天就能跑
    - SLAM(gmapping)：输出全局位姿，需要 odom+雷达+建图时间，AS5600 没到 -> 跑不了
    - 结论：最小闭环 = 视觉伺服。SLAM 是后续加分项。
    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
2026-10-13 feat(mechanical): 归档 3D 打印最终版（2026-10-12 v2-final）
    ## 来源
    U 盘 医疗服务/ 文件夹（10-12 14:16，比本机项目里的 10-05 版本新）
    ## 目录重组
    hardware/mechanical/
    ├── README.md 版本说明 + 打印注意事项
    ├── CAD/ SolidWorks 源文件
    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
